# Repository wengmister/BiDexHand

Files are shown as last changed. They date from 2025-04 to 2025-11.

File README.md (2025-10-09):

# BiDexHand: Open-Source 16-DoF Biomimetic Dexterous Hand
Author: [Zhengyang Kris Weng](https://wengmister.github.io/)   
[arXiv](https://arxiv.org/abs/2504.14712) | [OnShape](https://cad.onshape.com/documents/01cd86c3e9db901b13d9f00a/w/85362aa967854376c1ce3eaf/e/cdd4272996feef8877266f8c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) | [Blogpost](https://wengmister.github.io/#dexterous-hand)

Open source release of BiDexHand. This guide will help you build your own hand and get your started on the setup.

Biomimetic Dexterous Hand Demonstration (https://youtu.be/X8zVKlZNorc?si=lmVslFvECZyih0Kd)

# Overview

This is the open source release of the BiDexHand V4, a robotic hand featuring 16 degrees of freedom. It utilizes a cable-and-pulley system, with 15 servos arranged in `N configuration` to drive its 15 joints with tenden, and a 4-bar linkage driven 16th joint.

Each finger provides three degrees of freedom: metacarpal (MCP) adduction/abduction, MCP flexion/extension, and proximal interphalangeal (PIP) flexion/extension. A custom four-bar linkage at the distal end of each phalanx converts the PIP motion into a coupled movement at the distal interphalangeal (DIP) joint. The thumb is designed with four degrees of freedom, including carpometacarpal (CMC) adduction/abduction and flexion/extension, as well as MCP adduction/abduction and flexion/extension.

The hand is controlled through provided `ROS2` packages found in `/src`. It provides several modes to interface with the robot - `motion shadowing` and `servo input` streaming through `ROS2` topic, or direct `servo input` control through CLI. See packages in `/src` for more details.

**V4 Updates in a nutshell:**
- Updated single shear phalanx
- Added servo calibration modules
- Now using unified FeeTech servos (see [BOM](/BOM.md) update)
- Now using servo2040 for PWM builds
- Franka whole arm VR teleoperation (see [this repo](https://github.com/wengmister/franka-vr-teleop) for more details)

# Hardware Setup

STEP file for the cad asset can be found under `/cad_asset/_stp`, and individual STL file under `/cad_asset/_stl`. Additionally, you can find CAD hosted online on [OnShape](https://cad.onshape.com/documents/01cd86c3e9db901b13d9f00a/w/85362aa967854376c1ce3eaf/e/cdd4272996feef8877266f8c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).

See [BOM.md](/BOM.md) for more details.

For `V4`, build, flash and deploy `/scripts/Servo2040/servo2040_controller` to controller for the PWM version. Alternatively, use script from `V3` fork for SCS bus builds.
- You'll need `pico-sdk` and `pimoroni-pico` modules to build the PWM project.

# Environment Setup

This project is primarily tested on `ROS2-JAZZY`. To build locally, run:

    git clone https://github.com/wengmister/BiDexHand.git
    cd BiDexHand
    rosdep install --from-paths src -y --ignore-src

Finally, 

    colcon build
    . install/setup.bash

# VR Setup

If you plan to use Meta Quest for the motion shadowing demo, you can follow the build and deployment steps in [this repo](https://github.com/NU-MECH-ENG-495/vr-hand-tracking).

# Quickstart
### Hand Control

For motion shadowing:

    ros2 launch hand_motion_shadowing shadowing.launch.xml usb:=/dev/ttyACM0

For direct servo control:

    ros2 launch hand_servo_control multi_servo_control.launch.xml usb:=/dev/ttyACM0

Change usb port based on your device setting.

For Franka `MoveIT!` config demo:

    ros2 launch combined_fer_moveit_config demo.launch.py

### Franka Integration

For deploying on real Franka Fer, copy and build the following packages to your robot `station`:
- hand_rviz
- combined_fer_moveit_config

On station, run:

    ros2 launch combined_fer_moveit_config real.launch.py use_rviz:=false robot_ip:=[YOUR_ROBOT_IP]

On your laptop, run:

    ros2 launch combined_fer_moveit_config moveit_rviz.launch.py robot_ip:=[YOUR_ROBOT_IP]

See [this repo](https://github.com/wengmister/franka-vr-teleop) on details about whole arm teleoperation!

# Demo

### Mixed Reality Motion Shadowing      
MR

### Calibration
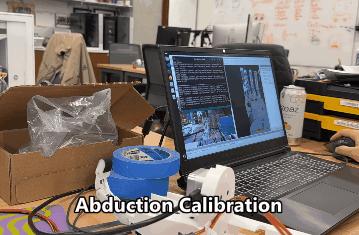
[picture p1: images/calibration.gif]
Calibration


### Franka FER Integration    
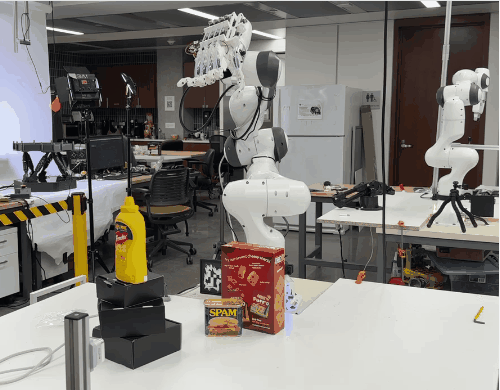
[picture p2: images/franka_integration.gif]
Franka


### Franka VR Teleoperation    
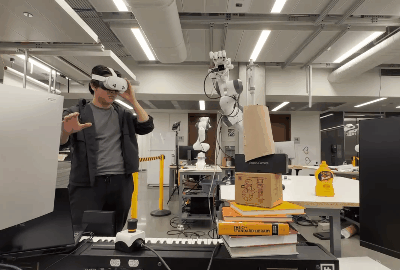
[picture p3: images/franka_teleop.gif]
Franka Teleop


# Citation
If you find this work helpful for your work or research, please consider citing as:

    @misc{weng2025bidexhand,
        title={BiDexHand: Design and Evaluation of an Open-Source 16-DoF Biomimetic Dexterous Hand}, 
        author={Zhengyang Kris Weng},
        year={2025},
        eprint={2504.14712},
        archivePrefix={arXiv},
        primaryClass={cs.RO},
        url={https://arxiv.org/abs/2504.14712}, 
    }

# License
MIT

# Related Repo
[Franka VR Teleop](https://github.com/wengmister/franka-vr-teleop)  
[VR Tracking App](https://github.com/wengmister/quest-wrist-tracker)  
[VR dex-retargeting](https://github.com/wengmister/vr-dex-retargeting)

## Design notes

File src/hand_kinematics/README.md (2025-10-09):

# Hand Kinematics C++ Node

A ROS2 C++ implementation of forward and inverse kinematics for BiDexHand with mechanical coupling between joints.

## Features

- Forward kinematics computation for all fingers (thumb, index, middle, ring, pinky)
- Inverse kinematics using Ceres optimization library
- Unified mechanical coupling between joints (PIP to DIP) using antiparallelogram model
- URDF-based robot description parsing
- ROS2 service interface for easy integration

## Dependencies

- ROS2 (tested with Jazzy)
- Eigen3
- Ceres Solver
- TinyXML2
- yaml-cpp

### Ubuntu Dependencies

```bash
sudo apt install ros-jazzy-rclcpp ros-jazzy-geometry-msgs ros-jazzy-std-msgs
sudo apt install libeigen3-dev libceres-dev libtinyxml2-dev libyaml-cpp-dev
```

## Building

```bash
# Create a workspace
mkdir -p ~/ros2_ws/src
cd ~/ros2_ws/src

# Clone or copy this package
# Copy your package files here

# Build
cd ~/ros2_ws
colcon build --packages-select hand_kinematics

# Source the workspace
source install/setup.bash
```

## Usage

### Running the Node

```bash
ros2 launch hand_kinematics hand_kinematics.launch.py urdf_file:=/path/to/your/hand.urdf
```

### ROS2 Services

#### Services Provided
- `/hand/forward_kinematics` (hand_kinematics/srv/ForwardKinematics) - Compute tip position from joint angles
- `/hand/inverse_kinematics` (hand_kinematics/srv/InverseKinematics) - Compute joint angles to reach target position

### Testing

Run the test client to see the node in action:

```bash
ros2 run hand_kinematics hand_kinematics_test_client
```

The test client will:
1. Call forward kinematics service with sample joint angles
2. Call inverse kinematics service with target positions
3. Display the results including success status and computed values

### Example Usage in Code

#### Using Forward Kinematics Service
```cpp
auto client = node->create_client<hand_kinematics::srv::ForwardKinematics>("hand/forward_kinematics");
auto request = std::make_shared<hand_kinematics::srv::ForwardKinematics::Request>();
request->chain_name = "index";
request->joint_angles_deg = {10.0, 20.0, 30.0};  // degrees

auto future = client->async_send_request(request);
```

#### Using Inverse Kinematics Service
```cpp
auto client = node->create_client<hand_kinematics::srv::InverseKinematics>("hand/inverse_kinematics");
auto request = std::make_shared<hand_kinematics::srv::InverseKinematics::Request>();
request->chain_name = "thumb";
request->target_position.x = 0.08;
request->target_position.y = 0.02;
request->target_position.z = 0.05;
request->initial_guess_deg = {0.0, 10.0, 5.0, 15.0};  // optional

auto future = client->async_send_request(request);
```

#### Using Command Line
```bash
# Forward Kinematics
ros2 service call /hand/forward_kinematics hand_kinematics/srv/ForwardKinematics "chain_name: 'index'
joint_angles_deg: [10.0, 20.0, 30.0]"

# Inverse Kinematics
ros2 service call /hand/inverse_kinematics hand_kinematics/srv/InverseKinematics "chain_name: 'thumb'
target_position:
  x: 0.08
  y: 0.02
  z: 0.05
initial_guess_deg: [0.0, 10.0, 5.0, 15.0]"
```

## Architecture

The main class `HandKinematics` handles:

1. **URDF Parsing**: Reads robot description from URDF file
2. **Kinematic Tree Building**: Constructs the kinematic tree
3. **Forward Kinematics**: Computes end-effector poses from joint angles
4. **Inverse Kinematics**: Solves for joint angles given target poses
5. **Mechanical Coupling**: Applies unified coupling between PIP and DIP joints

### Mechanical Coupling

The system implements unified coupling between:
- PIP (Proximal Interphalangeal) joints and DIP (Distal Interphalangeal) joints for all fingers including the thumb
- Uses the antiparallelgram model as described in linkage_analysis/antiparallelgram_model.pdf

## Configuration

### Finger Chains

The node supports the following finger chains:
- `index`: Index finger (ima_joint, imf_joint, ipf_joint) with tip joint i_tip_joint
- `middle`: Middle finger (mma_joint, mmf_joint, mpf_joint) with tip joint m_tip_joint
- `ring`: Ring finger (rma_joint, rmf_joint, rpf_joint) with tip joint r_tip_joint
- `pinky`: Pinky finger (pma_joint, pmf_joint, ppf_joint) with tip joint p_tip_joint
- `thumb`: Thumb (tcf_joint, tca_joint, tma_joint, tmf_joint) with tip joint t_tip_joint

### URDF Requirements

Your URDF should define:
- All joint names as specified in the finger chains
- Joint limits for proper IK constraints
- Proper parent-child relationships

## Troubleshooting

1. **IK doesn't converge**: Check that your target position is reachable and within joint limits
2. **Node crashes on startup**: Verify that the URDF path is correct and the file is valid
3. **Unexpected results**: Ensure that the joint names in the URDF match the expected names in the code

## License

MIT License

## Contributing

Feel free to submit issues and enhancement requests!
ros2 service call /hand/forward_kinematics hand_kinematics_cpp/srv/ForwardKinematics "chain_name: 'index'
joint_angles_deg: [10.0, 20.0, 30.0]"

# Inverse Kinematics
ros2 service call /hand/inverse_kinematics hand_kinematics_cpp/srv/InverseKinematics "chain_name: 'thumb'
target_position:
  x: 0.08
  y: 0.02
  z: 0.05
initial_guess_deg: [0.0, 10.0, 5.0, 15.0]"

## Architecture

The main class `HandKinematics` handles:

1. **URDF Parsing**: Reads robot description from URDF file
2. **Kinematic Tree Building**: Constructs the kinematic tree
3. **Forward Kinematics**: Computes end-effector poses from joint angles
4. **Inverse Kinematics**: Solves for joint angles given target poses
5. **Mechanical Coupling**: Applies coupling between PIP and DIP joints

### Mechanical Coupling

The system implements unified coupling between:
- PIP (Proximal Interphalangeal) joints and DIP (Distal Interphalangeal) joints for all fingers including the thumb
- Uses the antiparallelogram model as described in linkage_analysis/antiparallelgram_model.pdf

## Configuration

### Finger Chains

The node supports the following finger chains:
- `index`: Index finger (ima_joint, imf_joint, ipf_joint)
- `middle`: Middle finger (mma_joint, mmf_joint, mpf_joint)
- `ring`: Ring finger (rma_joint, rmf_joint, rpf_joint)
- `pinky`: Pinky finger (pma_joint, pmf_joint, ppf_joint)
- `thumb`: Thumb (tcf_joint, tca_joint, tma_joint, tmf_joint)

### URDF Requirements

Your URDF should define:
- All joint names as specified in the finger chains
- Joint limits for proper IK constraints
- Proper parent-child relationships

## Troubleshooting

1. **IK doesn't converge**: Check that your target position is reachable and within joint limits
2. **Node crashes on startup**: Verify that the URDF path is correct and the file is valid
3. **Unexpected results**: Ensure that the joint names in the URDF match the expected names in the code

## License

MIT License

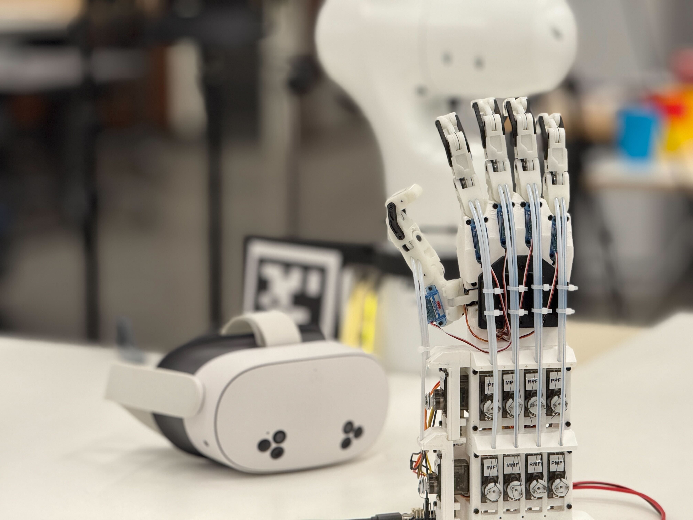
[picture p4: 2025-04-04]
images/preview.jpg

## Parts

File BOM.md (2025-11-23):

# Bill of Material

| ITEM NO. | PART NUMBER | DESCRIPTION | QTY. | COMMENTS |
|---|---|---|---|---|
| 1 | palm, base | 3D printed part | 1 |  |
| 2 | plx, base | 3D printed part | 4 |  |
| 3 | plx, knuckle | 3D printed part | 4 |  |
| 4 | plx, proximal | 3D printed part | 4 |  |
| 5 | plx, support | 3D printed part | 5 |  |
| 6 | plx, middle | 3D printed part | 5 |  |
| 7 | plx, distal | 3D printed part | 5 |  |
| 8 | plx, cover | 3D printed part | 4 |  |
| 9 | pulley, scs0009 | 3D printed part | 15 |  |
| 10 | thumb, base | 3D printed part | 1 |  |
| 11 | thumb, arm | 3D printed part | 1 |  |
| 12 | thumb, cmc | 3D printed part | 1 |  |
| 13 | thumb, bridge | 3D printed part | 1 |  |
| 14 | thumb, proximal | 3D printed part | 1 |  |
| 15 | thumb, mcp | 3D printed part | 1 |  |
| 16 | thumb, cover | 3D printed part | 1 |  |
| 17 | palm, coupler | 3D printed part | 1 |  |
| 18 | sleeve, servo rack top | 3D printed part | 2 |  |
| 19 | sleeve, servo rack back  | 3D printed part | 2 |  |
| 20 | sleeve, servo carriage | 3D printed part | 10 |  |
| 21 | sleeve, servo rack | 3D printed part | 1 |  |
| 22 | sleeve, servo single rack | 3D printed part | 1 |  |
| 23 | sleeve, servo single rack top | 3D printed part | 2 |  |
| 24 | sleeve, servo single rack back | 3D printed part | 1 |  |
| 25 | sleeve, base | 3D printed part | 1 |  |
| 26 | palm, guard | 3D printed part | 2 |  |
| 27 | [90323A605](https://www.mcmaster.com/90323A605) | 18-8 Stainless Steel Low-Profile Precision Shoulder Screw | 5 | McMaster-Carr component |
| 28 | [90323A608](https://www.mcmaster.com/90323A608) | 18-8 Stainless Steel Low-Profile Precision Shoulder Screw | 15 | McMaster-Carr component |
| 29 | [97307A111](https://www.mcmaster.com/97307A111) | Slotted 18-8 Stainless Steel Precision Shoulder Screw | 10 | McMaster-Carr component |
| 30 | [91290A021](https://www.mcmaster.com/91290A021) | Alloy Steel Socket Head Screw | 61 | McMaster-Carr component |
| 31 | [2705T112](https://www.mcmaster.com/2705T112) | Light Duty Dry-Running Flanged Sleeve Bearing | 26 | McMaster-Carr component |
| 32 | [98089A201](https://www.mcmaster.com/98089A201) | 18-8 Stainless Steel Round Shim | 16 | McMaster-Carr component |
| 33 | [92010A778](https://www.mcmaster.com/92010A778) | Passivated 18-8 Stainless Steel Phillips Flat Head Screw | 28 | McMaster-Carr component |
| 34 | [90323A604](https://www.mcmaster.com/90323A604) | 18-8 Stainless Steel Low-Profile Precision Shoulder Screw | 3 | McMaster-Carr component |
| 35 | [90323A612](https://www.mcmaster.com/90323A612) | 18-8 Stainless Steel Low-Profile Precision Shoulder Screw | 1 | McMaster-Carr component |
| 36 | [7119N113](https://www.mcmaster.com/7119N113) | Ultra-Low-Friction Oil-Embedded Sleeve Bearing | 1 | McMaster-Carr component |
| 37 | [6658K412](https://www.mcmaster.com/6658K412) | Oil-Embedded 841 Bronze Sleeve Bearing | 2 | McMaster-Carr component |
| 38 | [91290A015](https://www.mcmaster.com/91290A015) | Alloy Steel Socket Head Screw | 39 | McMaster-Carr component |
| 39 | [91292A028](https://www.mcmaster.com/91292A028) | 18-8 Stainless Steel Socket Head Screw | 10 | McMaster-Carr component |
| 40 | [2006N111](https://www.mcmaster.com/2006N111) | 302 Stainless Steel Corrosion-Resistant Compression Springs | 10 | McMaster-Carr component |
| 41 | [94510A370](https://www.mcmaster.com/94510A370) | Brass Screw-to-Expand Inserts | 10 | McMaster-Carr component |
| 42 | [91290A019](https://www.mcmaster.com/91290A019) | Alloy Steel Socket Head Screw | 14 | McMaster-Carr component |
| 43 | [91502A109](https://www.mcmaster.com/91502A109) | Blue-Dyed Zinc-Plated Alloy Steel Socket Head Screw | 2 | McMaster-Carr component |
| 44 | [91502A107](https://www.mcmaster.com/91502A107) | Blue-Dyed Zinc-Plated Alloy Steel Socket Head Screw | 4 | McMaster-Carr component |
| 45 | FeeTech FT90M Servo* | 9G servo motor, PWM | 16 | [Alibaba](https://www.alibaba.com/product-detail/Feetech-FT90M-Metal-Gear-Digital-Core_1601043147164.html) |
| 46 | Pimoroni Servo2040* | RP2040 Servo Shell | 1 | [Adafruit](https://www.adafruit.com/product/5437) |
| 47 | 6V 5A Power Supply | Alternatively use adjustable bench power supply | 1 | – |
| 48 | DuraBraid fishing wire | 40lb | As needed | [Amazon](https://www.amazon.com/SpiderWire-DuraBraid-Braid-Fishing-Line/dp/B0C69TLSHK) |
| 49 | 2mm zipties | Cable management | As needed | – |
| 50 | 3mm OD PTFE Tube |  | As needed | [Amazon](https://www.amazon.com/uxcell-Tubing-Printer-RepRap-16-4ft/dp/B07F64KQR1) |
| 51 | D405_Solid | Intel Realsense wrist camera | 1 |  |
| 52 | SCS009** | Feetech Servo Motor | 16 |  |
| 53 | scs_board** | Signal distribute board | 5 |  |
| 54 | FE-URT-1** | USB to TTL level shifter | 1 |  |
| 55 | ESP32** | MCU | 1 |  |

*PWM Control version  
**SCS Bus version

Small Feetech servo motor availability in the U.S. could be tight due to Tariffs and demands. You may want to build specific versions depending on what servo you can get.

3D Printed parts - While FDM works, SLA tends to yield better results for phalanx and thumb components.

## Assembly

phalanx++ 2

Refer to CAD under `cad_asset` or [OnShape repo](https://cad.onshape.com/documents/01cd86c3e9db901b13d9f00a/w/85362aa967854376c1ce3eaf/e/cdd4272996feef8877266f8c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) for assembly details.

---
If you're interested in contributing to the source CAD, please reach out to [me](wengmister@gmail.com).

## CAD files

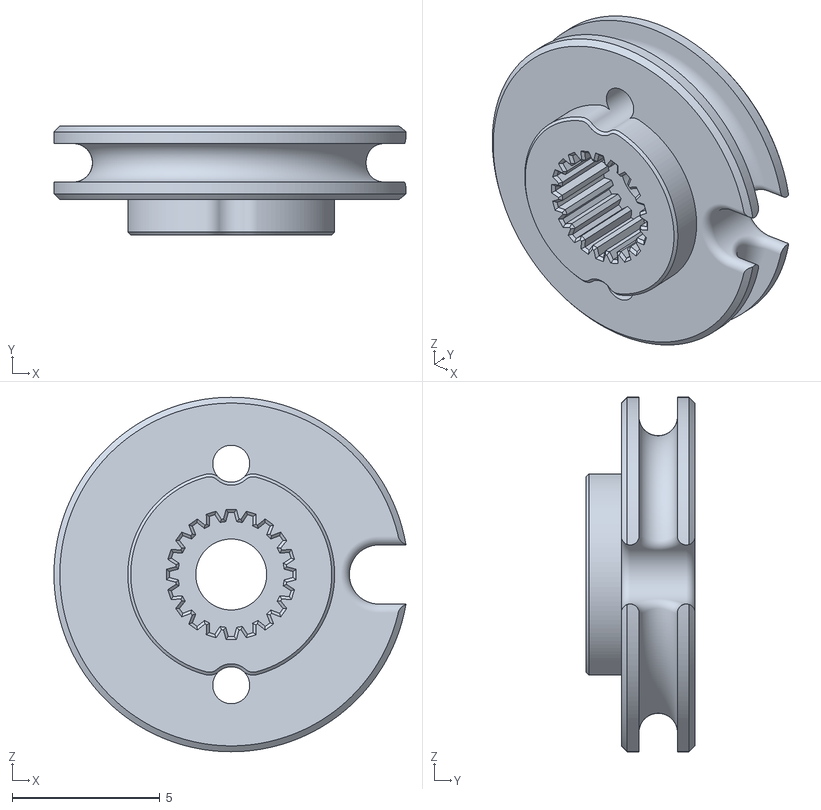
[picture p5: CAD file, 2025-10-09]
cad_asset/_stl/pulley, scs0009.STL
11.9 x 3.70 x 12.0

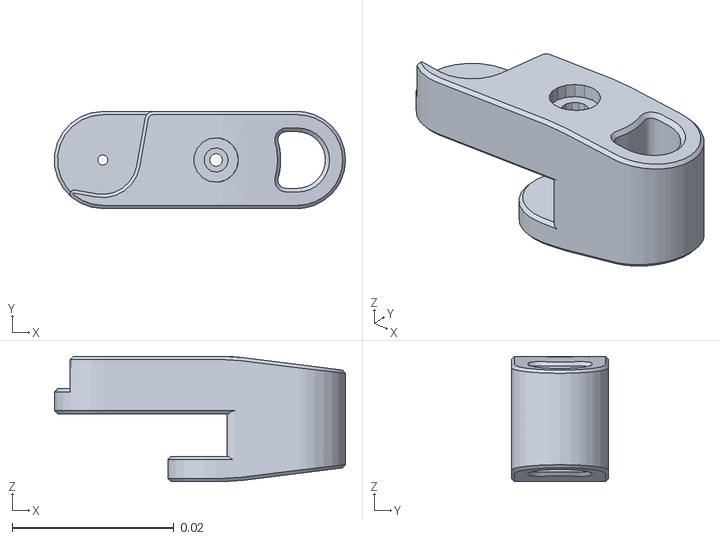
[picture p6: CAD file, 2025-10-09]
src/hand_rviz/urdf/meshes/tdf_link.STL
0.036 x 0.012 x 0.0155

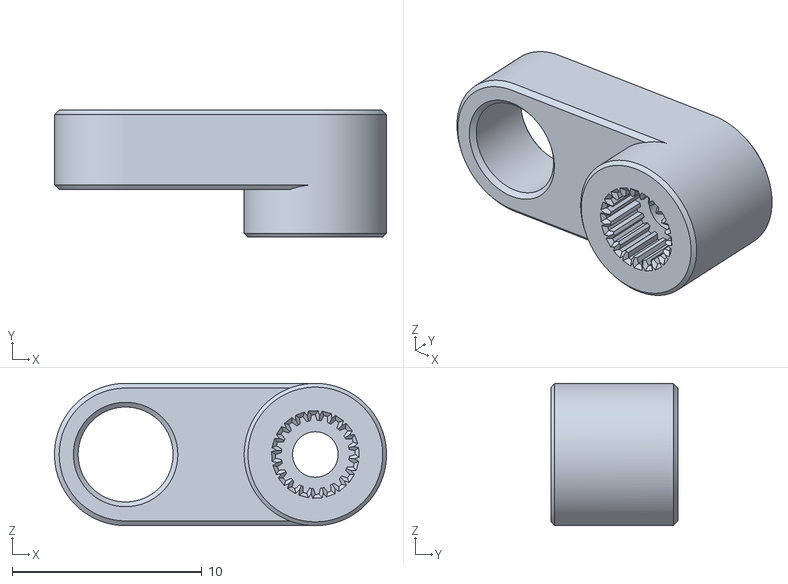
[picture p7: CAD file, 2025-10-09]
cad_asset/_stl/thumb, arm.STL
17.5 x 6.70 x 7.50

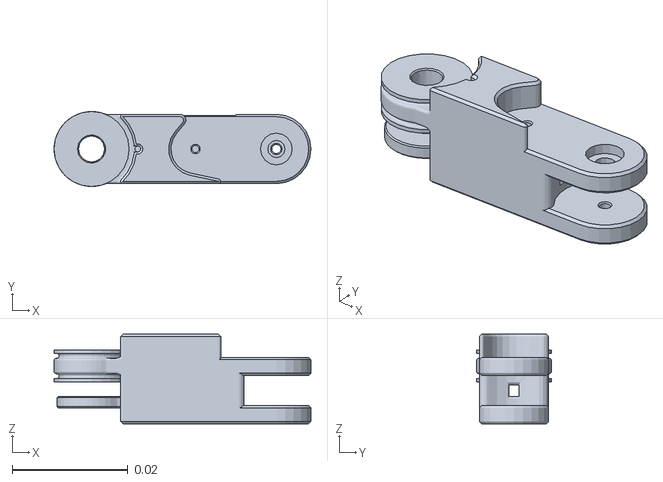
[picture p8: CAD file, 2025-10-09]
src/hand_rviz/urdf/meshes/pmf_link.STL
0.0445 x 0.013 x 0.0155

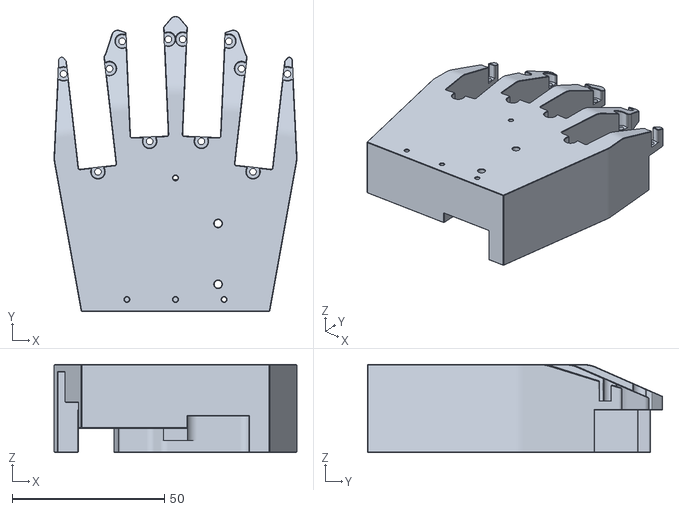
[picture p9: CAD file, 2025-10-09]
cad_asset/_stl/palm, base.STL
79.9 x 97.1 x 29.0

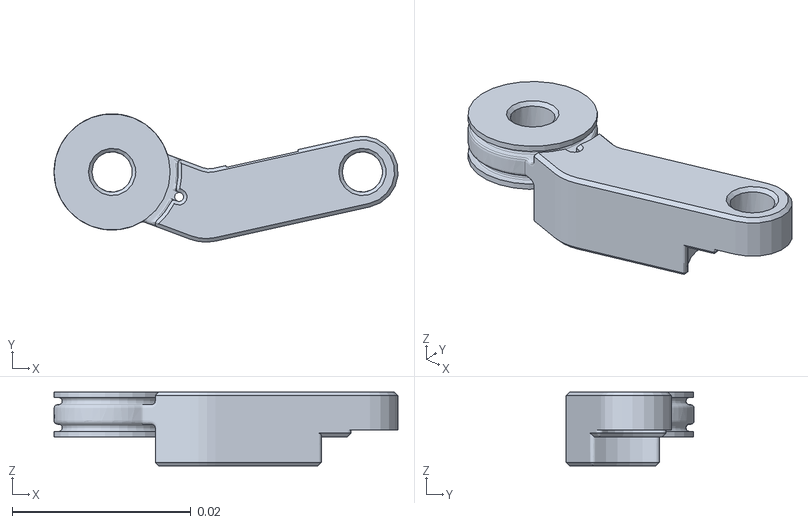
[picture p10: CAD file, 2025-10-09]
src/hand_rviz/urdf/meshes/tmf_link.STL
0.0385 x 0.0144 x 0.00825

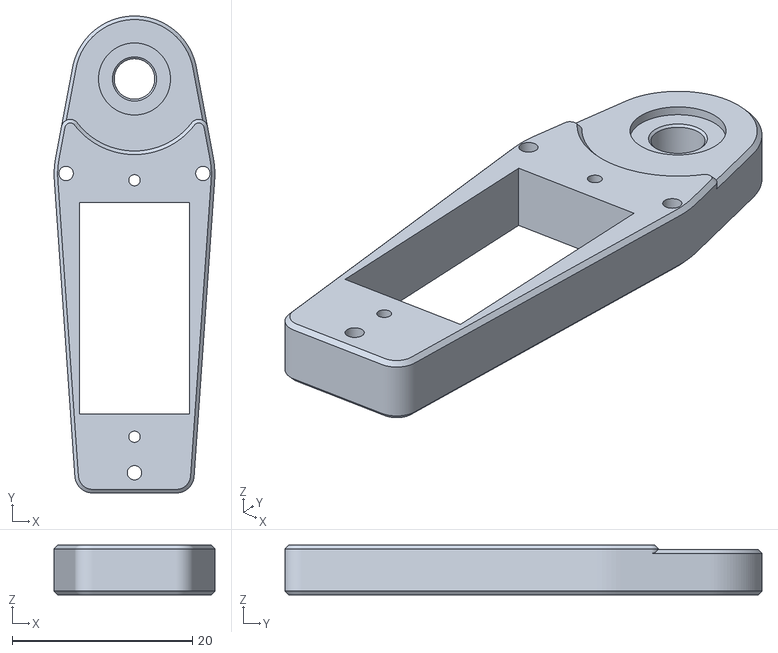
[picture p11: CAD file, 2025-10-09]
cad_asset/_stl/plx, base.STL
17.9 x 53.0 x 5.50

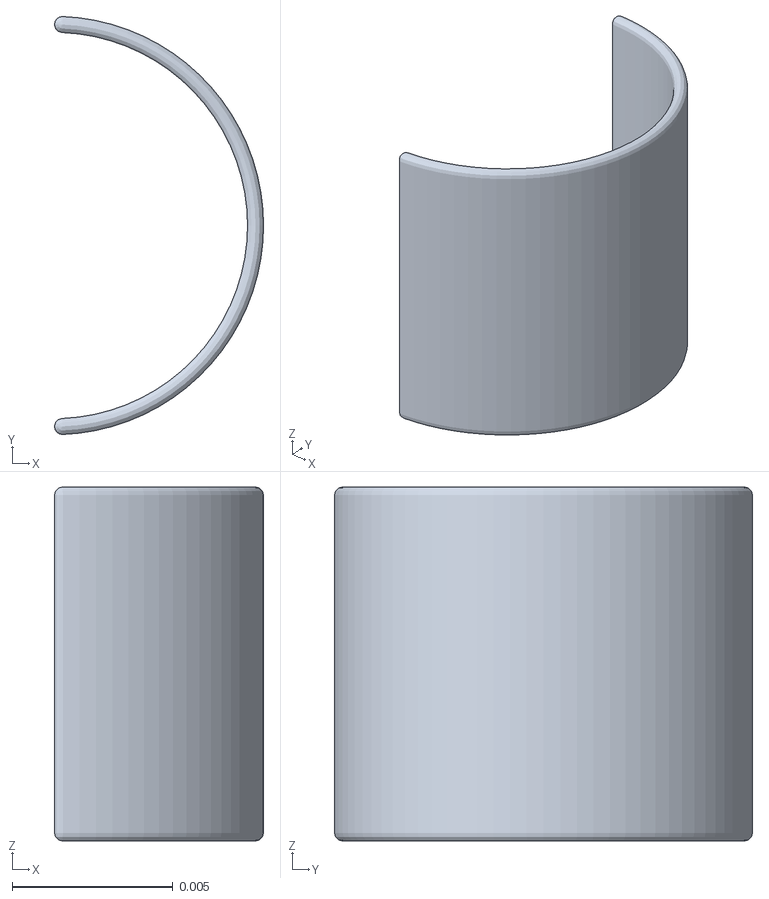
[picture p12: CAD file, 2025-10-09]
src/hand_rviz/urdf/meshes/m_tip_link.STL
0.0065 x 0.013 x 0.011

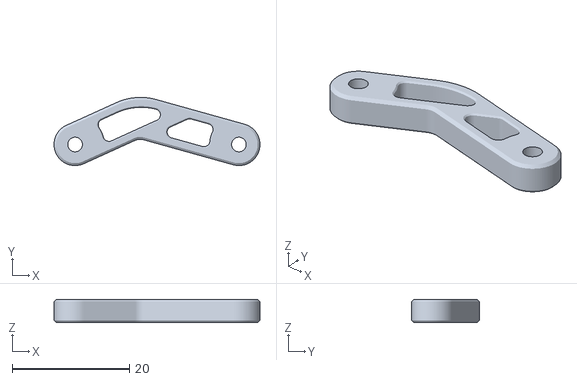
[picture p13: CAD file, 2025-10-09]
cad_asset/_stl/plx, support.STL
35.2 x 11.6 x 4.00

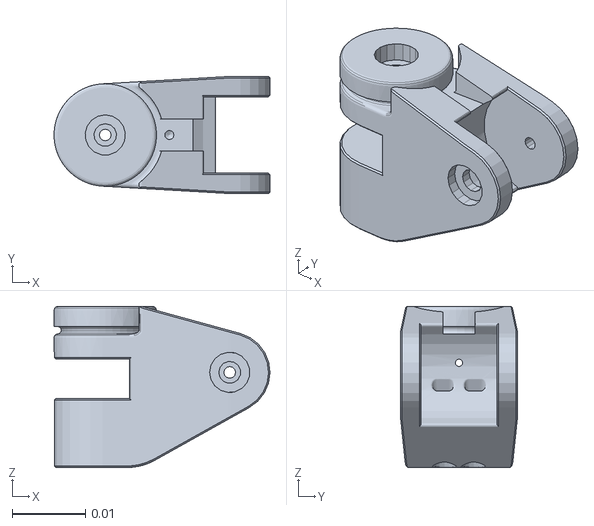
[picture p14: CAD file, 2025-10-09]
src/hand_rviz/urdf/meshes/rma_link.STL
0.0295 x 0.016 x 0.022

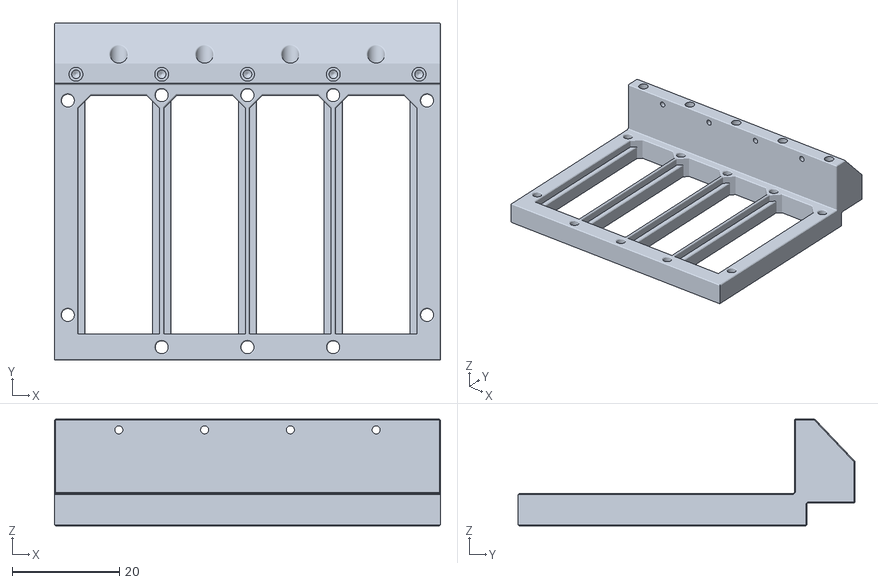
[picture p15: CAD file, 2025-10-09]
cad_asset/_stl/sleeve, servo rack back.STL
72.0 x 62.9 x 19.9

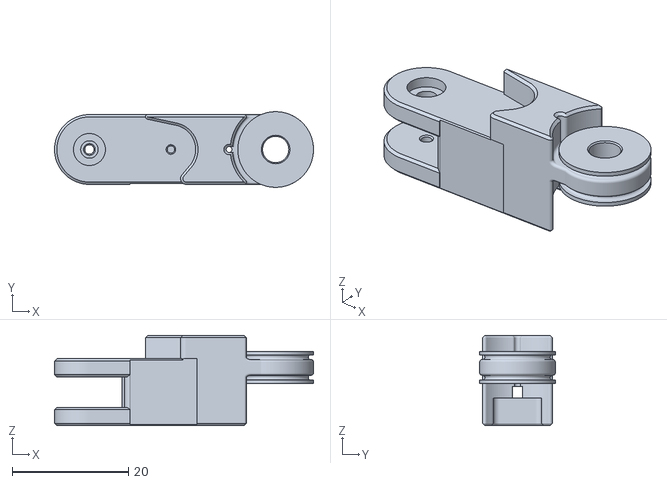
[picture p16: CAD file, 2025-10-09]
cad_asset/_stl/plx, proximal.STL
44.5 x 13.0 x 15.5

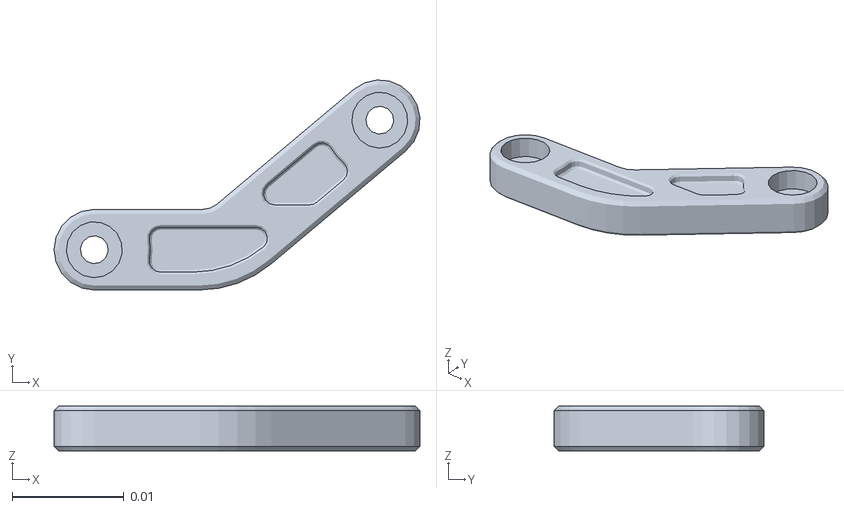
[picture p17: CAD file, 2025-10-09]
src/hand_rviz/urdf/meshes/tds_link.STL
0.0327 x 0.0188 x 0.004

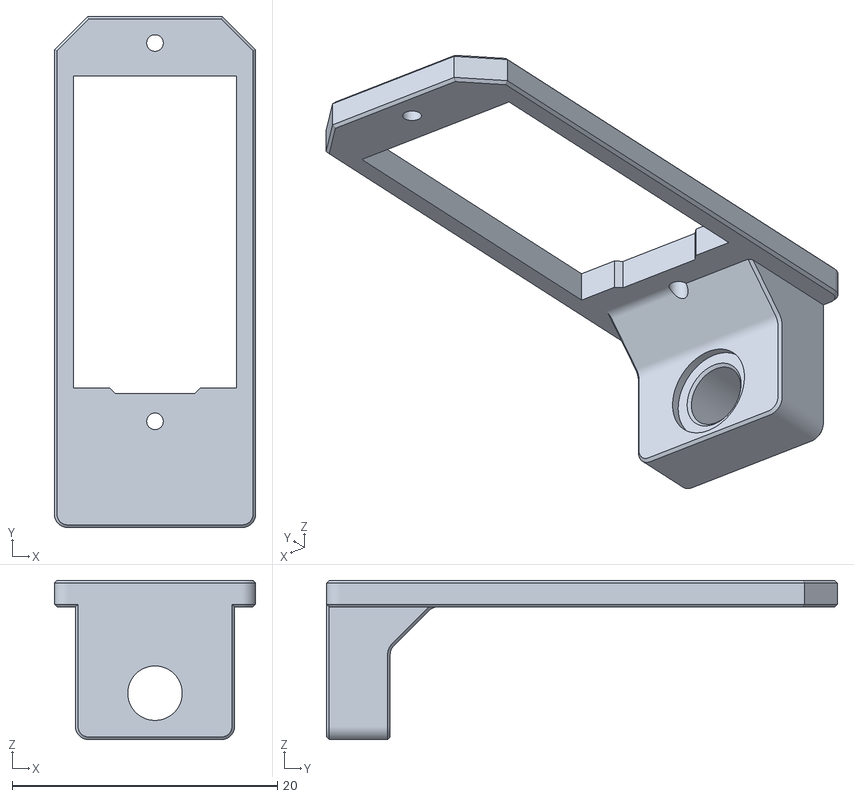
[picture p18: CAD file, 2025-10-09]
cad_asset/_stl/sleeve, servo carriage.STL
15.2 x 38.5 x 12.0

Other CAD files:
cad_asset/_stp/bidexhand v4.STEP
src/hand_rviz/urdf/meshes/imf_link.STL
src/hand_rviz/urdf/meshes/r_tip_link.STL
cad_asset/_stl/thumb, proximal.STL
cad_asset/_stl/palm, coupler.STL
cad_asset/_stl/palm, guard 2.STL
cad_asset/_stl/plx, cover.STL
cad_asset/_stl/plx, distal.STL
cad_asset/_stl/plx, knuckle.STL
cad_asset/_stl/plx, middle.STL
cad_asset/_stl/sleeve, base.STL
cad_asset/_stl/sleeve, servo rack top.STL
cad_asset/_stl/sleeve, servo rack.STL
cad_asset/_stl/sleeve, servo single rack back.STL
cad_asset/_stl/sleeve, servo single rack top.STL
cad_asset/_stl/sleeve, servo single rack.STL
cad_asset/_stl/thumb, base.STL
cad_asset/_stl/thumb, bridge.STL
cad_asset/_stl/thumb, cmc.STL
cad_asset/_stl/thumb, cover.STL
cad_asset/_stl/thumb, mcp.STL
src/hand_rviz/urdf/meshes/hand_base_link.STL
src/hand_rviz/urdf/meshes/i_tip_link.STL
src/hand_rviz/urdf/meshes/idf_link.STL
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

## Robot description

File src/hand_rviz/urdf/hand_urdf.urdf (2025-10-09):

<?xml version="1.0" encoding="utf-8"?>
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
<robot name="hand_rviz_urdf">
  <link name="hand_base_link">
    <inertial>
      <origin xyz="-0.000725570415579053 -0.0104080064888702 0.0230876216279809" rpy="0 0 0" />
      <mass value="1.41105557691145" />
      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
    </inertial>
    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
  </link>
  <link name="tcf_link">
    <inertial>
      <origin xyz="-0.0127681015251988 0.0064872186643618 0.000330864552872193" rpy="0 0 0" />
      <mass value="0.00505286263408417" />
      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
    </inertial>
    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
  </link>
  <joint name="tcf_joint" type="revolute">
    <origin xyz="-0.03305 -0.02155 0.0495" rpy="0 0 0" />
    <parent link="hand_base_link" />
    <child link="tcf_link" />
    <axis xyz="0 0 1" />
    <limit lower="-1.57" upper="0.175" effort="0" velocity="0" />
  </joint>
  <link name="tca_link">
    <inertial>
      <origin xyz="0.0105237383263635 -0.000433201383295542 0.00254229836481148" rpy="0 0 0" />
      <mass value="0.00511850580963509" />
      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
    </inertial>
    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
  </link>
  <joint name="tca_joint" type="revolute">
    <origin xyz="-0.024 0.016626 0.011678" rpy="2.7701 -1.0044 2.0034" />
    <parent link="tcf_link" />
    <child link="tca_link" />
    <axis xyz="0 0 1" />
    <limit lower="-0.5" upper="1" effort="0" velocity="0" />
  </joint>
  <link name="tma_link">
    <inertial>
      <origin xyz="0.0115738759402629 -0.000303204414334148 -0.00174482181200082" rpy="0 0 0" />
      <mass value="0.00329743064165085" />
      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
    </inertial>
    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
  </link>
  <joint name="tma_joint" type="revolute">
    <origin xyz="0.025 0.000975 0.000475" rpy="-1.5708 0 0" />
    <parent link="tca_link" />
    <child link="tma_link" />
    <axis xyz="0 0 1" />
    <limit lower="-1.2" upper="0.7" effort="0" velocity="0" />
  </joint>
  <link name="tmf_link">
    <inertial>
      <origin xyz="0.0119380012691961 -0.00180717018424088 -0.00119615806984238" rpy="0 0 0" />
      <mass value="0.00178293997137009" />
      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
    </inertial>
    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
  </link>
  <joint name="tmf_joint" type="revolute">
    <origin xyz="0.023 -0.000125 -0.003475" rpy="1.5708 -1.1468 0" />
    <parent link="tma_link" />
    <child link="tmf_link" />
    <axis xyz="0 0 1" />
    <limit lower="-0.650" upper="1.57" effort="0" velocity="0" />
  </joint>
  <link name="tdf_link">
    <inertial>
      <origin xyz="0.000802743353210698 -0.000155618657950204 0.00275199039461954" rpy="0 0 0" />
      <mass value="0.00311228154218926" />
      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
    </inertial>
    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
  </link>
  <joint name="tdf_joint" type="revolute">
    <origin xyz="0.028 0 0" rpy="0 0 0.42403" />
    <parent link="tmf_link" />
    <child link="tdf_link" />
    <axis xyz="0 0 1" />
    <limit lower="-0.175" upper="1.25" effort="0" velocity="0" />
  </joint>
  <link name="t_tip_link">
    <inertial>
      <origin xyz="0.00180286824371704 3.90345999690123E-08 -6.31439345255558E-16" rpy="0 0 0" />
      <mass value="0.000106342041717247" />
      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
    </inertial>
    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
  </link>
  <joint name="t_tip_joint" type="fixed">
    <origin xyz="0.0122 0 0.001625" rpy="0 0 0" />
    <parent link="tdf_link" />
    <child link="t_tip_link" />
    <axis xyz="0 0 0" />
  </joint>
  <link name="tds_link">
    <inertial>
      <origin xyz="0.0135308220531408 0.00375751103141848 0.000893631122538648" rpy="0 0 0" />
      <mass value="0.000835750928421176" />
      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
    </inertial>
    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
  </link>
  <joint name="tds_joint" type="revolute">
    <origin xyz="0.009 -0.006425 -0.003475" rpy="1.5708 0.0019569 0" />
    <parent link="tma_link" />
    <child link="tds_link" />
    <axis xyz="0 0 1" />
    <limit lower="-0.175" upper="1.25" effort="0" velocity="0" />
    <mimic joint="tdf_joint" multiplier="1" offset="0" />
  </joint>
  <link name="ima_link">
    <inertial>
      <origin xyz="0.00503464484796538 5.98272297764428E-05 -0.00177249288426803" rpy="0 0 0" />
      <mass value="0.00449002294753804" />
      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
    </inertial>
    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
  </link>
  <joint name="ima_joint" type="revolute">
    <origin xyz="-0.030453 -0.042025 0.11347" rpy="1.5708 -1.4573 3.1416" />
    <parent link="hand_base_link" />
    <child link="ima_link" />
    <axis xyz="0 0 1" />
    <limit lower="-0.436" upper="0.436" effort="0" velocity="0" />
  </joint>
  <link name="imf_link">
    <inertial>
      <origin xyz="0.0157681146549905 -8.39248010623119E-05 -0.000586678883075314" rpy="0 0 0" />
      <mass value="0.00428037699515229" />
      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
    </inertial>
    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
  </link>
  <joint name="imf_joint" type="revolute">
    <origin xyz="0.017 0 0.0004" rpy="1.5708 0 0" />
    <parent link="ima_link" />
    <child link="imf_link" />
    <axis xyz="0 0 1" />
    <limit lower="-1.57" upper="1.57" effort="0" velocity="0" />
  </joint>
  <link name="ipf_link">
    <inertial>
      <origin xyz="0.0119380016101945 -0.00180717011704587 -0.0028211578621919" rpy="0 0 0" />
      <mass value="0.0017829399503603" />
      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
    </inertial>
    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
  </link>
  <joint name="ipf_joint" type="revolute">
    <origin xyz="0.032 0 0" rpy="0 0 1.1468" />
    <parent link="imf_link" />
    <child link="ipf_link" />
    <axis xyz="0 0 1" />
    <limit lower="-0.650" upper="1.57" effort="0" velocity="0" />
  </joint>
  <link name="idf_link">
    <inertial>
      <origin xyz="0.002387742591975 -0.000189373670521353 0.000969315817086848" rpy="0 0 0" />
      <mass value="0.00334446738731233" />
      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
    </inertial>
    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
  </link>
  <joint name="idf_joint" type="revolute">
    <origin xyz="0.028 0 0" rpy="0 0 0.42403" />
    <parent link="ipf_link" />
    <child link="idf_link" />
    <axis xyz="0 0 1" />
    <limit lower="-0.175" upper="1.25" effort="0" velocity="0" />
  </joint>
  <link name="i_tip_link">
    <inertial>
      <origin xyz="0.0017968 -1.9457E-08 -1.8041E-16" rpy="0 0 0" />
      <mass value="0.00010634" />
      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
    </inertial>
    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
  </link>
  <joint name="i_tip_joint" type="fixed">
    <origin xyz="0.016206 0 0" rpy="0 0 0" />
    <parent link="idf_link" />
    <child link="i_tip_link" />
    <axis xyz="0 0 0" />
  </joint>
  <link name="ids_link">
    <inertial>
      <origin xyz="0.013532 0.0036871 0.0010097" rpy="0 0 0" />
      <mass value="0.00089722" />
      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
    </inertial>
    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
  </link>
  <joint name="ids_joint" type="revolute">
    <origin xyz="0.018 0 0.004675" rpy="0 0 -0.0019569" />
    <parent link="imf_link" />
    <child link="ids_link" />
    <axis xyz="0 0 1" />
    <limit lower="-0.175" upper="1.25" effort="0" velocity="0" />
    <mimic joint="idf_joint" multiplier="1" offset="0" />
  </joint>
  <link name="mma_link">
    <inertial>
      <origin xyz="0.00503463550199068 5.98300126588075E-05 -0.00177249465586118" rpy="0 0 0" />
      <mass value="0.00449001647184619" />
      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
    </inertial>
    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
  </link>
  <joint name="mma_joint" type="revolute">
    <origin xyz="-0.010408 -0.042025 0.12371" rpy="1.5708 -1.5272 -3.1416" />
    <parent link="hand_base_link" />
    <child link="mma_link" />
    <axis xyz="0 0 1" />
    <limit lower="-0.436" upper="0.436" effort="0" velocity="0" />
  </joint>
  <link name="mmf_link">
    <inertial>
      <origin xyz="0.0157681146598199 -8.39247976679369E-05 -0.000586678874241761" rpy="0 0 0" />
      <mass value="0.00428037699020959" />
      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
    </inertial>
    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
  </link>
  <joint name="mmf_joint" type="revolute">
    <origin xyz="0.017 0 0.0004" rpy="1.5708 0 0" />
    <parent link="mma_link" />
    <child link="mmf_link" />
    <axis xyz="0 0 1" />
    <limit lower="-1.57" upper="1.57" effort="0" velocity="0" />
  </joint>
  <link name="mpf_link">
    <inertial>
      <origin xyz="0.0119380016426112 -0.00180717004813466 -0.00282115778359655" rpy="0 0 0" />
      <mass value="0.00178293992081719" />
      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
    </inertial>
    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
  </link>
  <joint name="mpf_joint" type="revolute">
    <origin xyz="0.032 0 0" rpy="0 0 1.1468" />
    <parent link="mmf_link" />
    <child link="mpf_link" />
    <axis xyz="0 0 1" />
    <limit lower="-0.650" upper="1.57" effort="0" velocity="0" />
  </joint>
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

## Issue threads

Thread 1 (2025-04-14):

Request for Guidance on Quest3s Hand/Finger Tracking Setup

AsahelLee, 2025-04-14:
Hello! 👋 First, thank you for creating this awesome project! I’m exploring hand and finger tracking capabilities with the Meta Quest3s and would love to integrate its wrist pose and finger joint data into my workflow.

Could you kindly share guidance on:

Setup Steps:
Any specific device configurations or permissions needed for hand tracking? Does your project use OpenXR, Oculus Integration, or another SDK/API to fetch hand-tracking data? I noticed your setup involves a USB-C connection to stream pose data. Are there specific driver or ADB configurations needed for this?

Dependencies:
Are there required SDKs, plugins, or project settings (e.g., Unity/Unreal versions, hand-tracking profiles) to ensure compatibility? Does the project rely on the third-party libraries for data streaming?

If there’s existing documentation, tutorials, or code snippets, I’d greatly appreciate a pointer! Thank you for your time and amazing work! 🙌

wengmister, 2025-04-14:
Hi - the VR project is actually in my other repo: https://github.com/NU-MECH-ENG-495/vr-hand-tracking. I'll update README  to include this project as well - thanks for pointing that out.

You will need to build and deploy the UnityProject via Unity to your quest headset. I used OXR hand for it and you can tweak the c# script/widget to customize the target and UI.

Closed 2025-04-14.

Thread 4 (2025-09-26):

Parts and components issues

a357450371-cmyk, 2025-09-26:
Hi there, dear author. I am currently researching the hand model you designed. While organizing the STL files, I noticed that the structure shown in the thumb CMC STL file is different from that of the hand in your overall assembly STEP file — it seems the CMC part has a few more components than the one in the overall assembly. Could you please advise on the reason for this? Thank you.

wengmister, 2025-09-29:
> > [您好，这里托管的版本实际上略有过时。我正在OnShape](https://cad.onshape.com/documents/01cd86c3e9db901b13d9f00a/w/85362aa967854376c1ce3eaf/e/cdd4272996feef8877266f8c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)上托管一个最新版本。我现在还有很多其他要务，但我很快就会发布一个版本来澄清一些事情。
>
> Thank you for your reply. Currently, I am pursuing a graduate degree, and my research focus is on dexterous hands. Could I directly make structural and control modifications on your dexterous hand in the future? In my thesis, I will cite your thesis.

Certainly, please do. The OnShape version should be a good baseline. Of you would like to get access to SolidWorks source file, just let me know (you'll need SW2023+)

a357450371-cmyk, 2025-10-01:
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

If such a thing exists, that would be even better. Currently, our research group is attempting to replicate your ingenious hand as the basis for our in-depth study.

wengmister, 2025-10-02:
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

Just added you to the repo. Let me know if anything is missing there since I haven't been working on this for a while. I'll try to give this repo an update soon.

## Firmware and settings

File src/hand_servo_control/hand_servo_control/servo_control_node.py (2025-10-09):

import rclpy
from rclpy.node import Node

from hand_servo_interfaces.srv import ServoCommands
from std_msgs.msg import Float32MultiArray
import serial

class ServoControlNode(Node):
    def __init__(self):
        super().__init__('servo_control_node')
        
        # Declare parameters
        self.declare_parameter('usb_port', '/dev/ttyUSB1')
        self.declare_parameter('mode', 'cli')
        
        # Retrieve parameter values
        usb_port = self.get_parameter('usb_port').value
        self.mode = self.get_parameter('mode').value
        
        # Attempt to open the serial connection using the provided USB port
        try:
            self.serial = serial.Serial(usb_port, 115200, timeout=1)
            self.get_logger().info(f'\033[94mConnected to USB port: {usb_port}\033[0m')
        except Exception as e:
            self.get_logger().error(f'Failed to connect to USB port {usb_port}: {e}')
            rclpy.shutdown()
            return
        
        # Setup depending on mode
        if self.mode == 'cli':
            # Create the ROS service for CLI mode
            self.srv = self.create_service(
                ServoCommands,
                'set_servo_positions',
                self.handle_set_servo_positions
            )
            self.get_logger().info('\033[94mCLI mode: service /set_servo_positions active.\033[0m')
        
        elif self.mode == 'streaming':
            # Create subscription to /hand_servo_input for streaming mode
            self.subscription = self.create_subscription(
                Float32MultiArray,
                '/hand_servo_input',
                self.servo_input_callback,
                10
            )
            self.get_logger().info('\033[94mStreaming mode: subscribed to /hand_servo_input.\033[0m')
        
        self.get_logger().info('\033[92mServo control node initialized.\033[0m')

    def handle_set_servo_positions(self, request, response):
        """Service callback for setting servo positions in CLI mode."""
        if len(request.channels) != len(request.positions):
            response.success = False
            self.get_logger().error('Mismatched channel and position arrays')
            return response
        
        commands = []
        for ch, pos in zip(request.channels, request.positions):
            commands.append(f"{ch},{pos:.3f}")
        command_string = ';'.join(commands) + '\n'
        
        try:
            self.serial.write(command_string.encode())
            # self.get_logger().info(f'Sent command: {command_string.strip()}')
            response.success = True
        except Exception as e:
            self.get_logger().error(f'Failed to send command: {e}')
            response.success = False
        
        return response

    def servo_input_callback(self, msg):
        """Subscriber callback for streaming servo positions."""
        # Expect exactly 16 joint angles
        if len(msg.data) != 16:
            self.get_logger().error(
                f"Received {len(msg.data)} angles, but expected 16."
            )
            return
        
        # Channel from 0-15
        commands = []
        for i, pos in enumerate(msg.data):
            commands.append(f"{i},{pos:.3f}")
        command_string = ';'.join(commands) + '\n'
        
        try:
            self.serial.write(command_string.encode())
            self.get_logger().debug(f'Sent command: {command_string.strip()}')
        except Exception as e:
            self.get_logger().error(f'Failed to send command: {e}')

def main(args=None):
    rclpy.init(args=args)
    node = ServoControlNode()
    try:
        rclpy.spin(node)
    except KeyboardInterrupt:
        pass
    finally:
        node.destroy_node()
        rclpy.shutdown()

if __name__ == '__main__':
    main()

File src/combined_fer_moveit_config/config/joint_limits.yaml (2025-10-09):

# joint_limits.yaml allows the dynamics properties specified in the URDF to be overwritten or augmented as needed
# Specific joint properties can be changed with the keys [max_position, min_position, max_velocity, max_acceleration]
# Joint limits can be turned off with [has_velocity_limits, has_acceleration_limits]
# These limits are taken from https://support.franka.de/docs/control_parameters.html

default_velocity_scaling_factor: 0.1
default_acceleration_scaling_factor: 0.1

joint_limits:
  fer_joint1:
    max_position: 2.8973
    min_position: -2.8973
    has_velocity_limits: true
    max_velocity: 2.1750
    has_acceleration_limits: true
    max_acceleration: 15.0
  fer_joint2:
    max_position: 1.7628
    min_position: -1.7628
    has_velocity_limits: true
    max_velocity: 2.1750
    has_acceleration_limits: true
    max_acceleration: 7.5
  fer_joint3:
    max_position: 2.8973
    min_position: -2.8973
    has_velocity_limits: true
    max_velocity: 2.1750
    has_acceleration_limits: true
    max_acceleration: 10.0
  fer_joint4:
    max_position: -0.0698
    min_position: -3.0718
    has_velocity_limits: true
    max_velocity: 12.5
    has_acceleration_limits: true
    max_acceleration: 12.5
  fer_joint5:
    max_position: 2.8973
    min_position: -2.8973
    has_velocity_limits: true
    max_velocity: 2.6100
    has_acceleration_limits: true
    max_acceleration: 15.0
  fer_joint6:
    max_position: 3.7525
    min_position: -0.0175
    has_velocity_limits: true
    max_velocity: 2.6100
    has_acceleration_limits: true
    max_acceleration: 20.0
  fer_joint7:
    max_position: 1.750
    min_position: -0.350
    has_velocity_limits: true
    max_velocity: 2.6100
    has_acceleration_limits: true
    max_acceleration: 20.0
  fer_finger_joint1:
    max_position: 0.04
    min_position: 0.00
    has_velocity_limits: true
    max_velocity: 0.2
    has_acceleration_limits: true
    max_acceleration: 20.0
  fer_finger_joint2:
    max_position: 0.04
    min_position: 0.00
    has_velocity_limits: true
    max_velocity: 0.2
    has_acceleration_limits: true
    max_acceleration: 20.0

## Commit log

2025-04-04 V3 Release
    [combined_arm.srdf.xacro, combined_arm.xacro, combined_description.xacro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]
2025-04-07 BOM and STL release
    [PALM, BASE.STL, PALM, COUPLER.STL, PALM, PTFE GUARD.STL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]
2025-04-14 Added servo GUI, README video embed and BOM update
2025-04-22 URDF update and arxiv preprint
    [hand_base_link.STL, hand_urdf.urdf, hand_urdf_cf.urdf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]
2025-06-26 V4 CAD updates
    [PALM, BASE.STL, PALM, COUPLER.STL, PALM, PTFE GUARD.STL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]
2025-07-12 BOM v4 updates
2025-10-09 Updated V4 BOM
2025-10-09 STL and BOM updates
    [palm, base.STL, palm, coupler.STL, palm, guard 2.STL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]
2025-10-09 STEP update
    [bdhand v4.STEP, bidexhand v4.STEP]
2025-10-09 Update BOM links
    Added an image and updated assembly reference link in BOM.
2025-11-23 Update BOM.md: fix typos in 2 items
